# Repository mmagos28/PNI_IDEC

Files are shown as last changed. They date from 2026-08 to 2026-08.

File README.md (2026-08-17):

# PNI_IDEC
Central repository for IDEC documentation, design files, software, procedures, and technical resources supporting engineering, prototyping, fabrication, and research projects.
## License

This design folder is licensed under the CERN Open Hardware Licence Version 2 - Permissive (CERN-OHL-P-2.0). See [LICENSE](LICENSE) for the full license text.

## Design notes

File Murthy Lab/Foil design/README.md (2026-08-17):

# Foil Design

This folder contains the design files for the foil used with the fly holder assembly jig.

## Files

- `FlyMetal_AL_M_S Drawing v2.pdf`: manufacturing drawing.
- `FlyMetal_AL_M_S.f3d`: Fusion 360 design file.
- `FlyMetal_AL_M_S.step`: STEP file for CAD review or manufacturing workflows.

## Manufacturing Notes

- Tolerances: +/- 0.002 in.
- Material: 0.001 in stainless steel 316, annealed.
## License

This design folder is licensed under the CERN Open Hardware Licence Version 2 - Permissive (CERN-OHL-P-2.0). See [LICENSE](LICENSE) for the full license text.

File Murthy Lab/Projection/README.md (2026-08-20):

# Projection Calibration Code

This folder contains MATLAB code for calibrating the dome projection system. The main workflow is controlled from `ConfigureProjectorOnline.m`, which lets the user enter the physical measurements of the system, update calibration parameters, preview the projection geometry, and generate the `calibratedBallImage.data` file used by the projection pipeline.

Before running the code, download this full `Projection` folder to your computer and work from the local copy. MATLAB must be able to access the `.m`, `.fig`, `.mat`, `.data`, and `v2` files from the same local folder structure.

## Main Files

- `ConfigureProjectorOnline.m`: main calibration GUI. This is the recommended entry point.
- `generateDome_MASM.m`: computes the dome/mirror/projector geometry and writes `calibratedBallImage.data`.
- `coords.mat`: stores the current calibration coordinates used by the GUI.
- `calibratedBallImage.data`: generated calibration map.
- `v2/generateCalibrationPatternV2.m`: visual grid helper used as an auxiliary calibration view.

## Screen Dimension Reference

The Mini VR projection documentation describes the dome screen as a styrofoam sphere with an 18 inch outer diameter and a 16 inch inner diameter. Therefore, the default spherical screen radius used in this calibration folder is `proj_param_Rs = 8` inches.

Reference: https://braincogs.github.io/building/projection.html

The screen center coordinates (`proj_param_xsm`, `proj_param_ysm`, `proj_param_zsm`) still need to be measured on the actual rig relative to the animal eyes. The documentation provides the screen size, but not the final center position for each assembled setup.
## Basic Workflow

1. Measure the original physical geometry of the projection system.

   Measure the screen, mirror, and projector positions as carefully as possible. The calibration depends on these values, so the initial geometry should be based on the real system rather than guessed values.

2. Open the calibration GUI in MATLAB.

   ```matlab
   cd('C:\Users\ms2910\OneDrive - Princeton University\Documents\GitHub\IDEC\PNI_IDEC\Murthy Lab\Projection')
   ConfigureProjectorOnline
   ```

3. Enter the measured values in the corresponding fields.

   The main coordinate groups are:

   - `screenRadius`, `screenX`, `screenY`, `screenZ`
   - `mirrorRadius`, `mirrorX`, `mirrorY`, `mirrorZ`
   - `projectorX`, `projectorY`, `projectorZ`
   - `x0`, `y0`, `x1`, `y1`, `x2`, `y2`

   The screen, mirror, and projector values describe the physical layout. The `x0/y0`, `x1/y1`, and `x2/y2` values are used to scale and shift the projected coordinates during calibration.

4. Regenerate the projection.

   Press the regenerate button in the GUI. In the normal dome mode, the code calls `generateDome_MASM.m`, updates the projection figure, and writes `calibratedBallImage.data`.

5. Save the coordinates.

   Use the save option in the GUI after the system is aligned. The values are stored in `coords.mat` and loaded again the next time the GUI is opened.

## Visual Grid Mode

`ConfigureProjectorOnline.m` includes a `Visual grid` checkbox. This mode is intended as an auxiliary calibration view.

- When `Visual grid` is off, the GUI uses the normal dome calibration workflow and generates `calibratedBallImage.data`.
- When `Visual grid` is on, the GUI draws a polar azimuth/elevation grid using the same dome/mirror/projector geometry. This makes it easier to see how changes in the calibration parameters affect the projected image.

The visual grid is not a replacement for the final calibration file. It is a reference pattern to help align the system before returning to the normal dome mode and generating the final `calibratedBallImage.data`.

## Notes

- Start with accurate physical measurements, then use the GUI controls for fine adjustment.
- If the displayed projection does not update after code changes, clear MATLAB's cached functions:

  ```matlab
  close all force
  clear ConfigureProjectorOnline generateDome_MASM generateCalibrationPatternV2
  rehash toolboxcache
  ConfigureProjectorOnline
  ```

- `visualizeCalibratedBallImage.m` is kept as a manual debugging tool, but it is no longer opened automatically during calibration.

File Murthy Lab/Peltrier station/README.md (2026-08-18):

# Peltier Station

This folder contains CAD files and reference images for a Peltier-based station used with fly holders. The design provides a working platform for positioning the fly holder over a temperature-controlled Peltier module while keeping the surrounding setup accessible for imaging, manipulation, and alignment.

## Files

- `base-peltrier-station.step`: editable CAD model for the station base.
- `base-peltrier-station.stl`: mesh file for manufacturing the station base.
- `Fly-Holder-peltrier-station.step`: editable CAD model for the fly holder interface.
- `Fly-Holder-peltrier-station.stl`: mesh file for manufacturing the fly holder interface.
- `peltrier-station-new_prices_only.xlsx`: price list / bill of materials reference for the station components.

## Design Preview

<table>
  <tr>
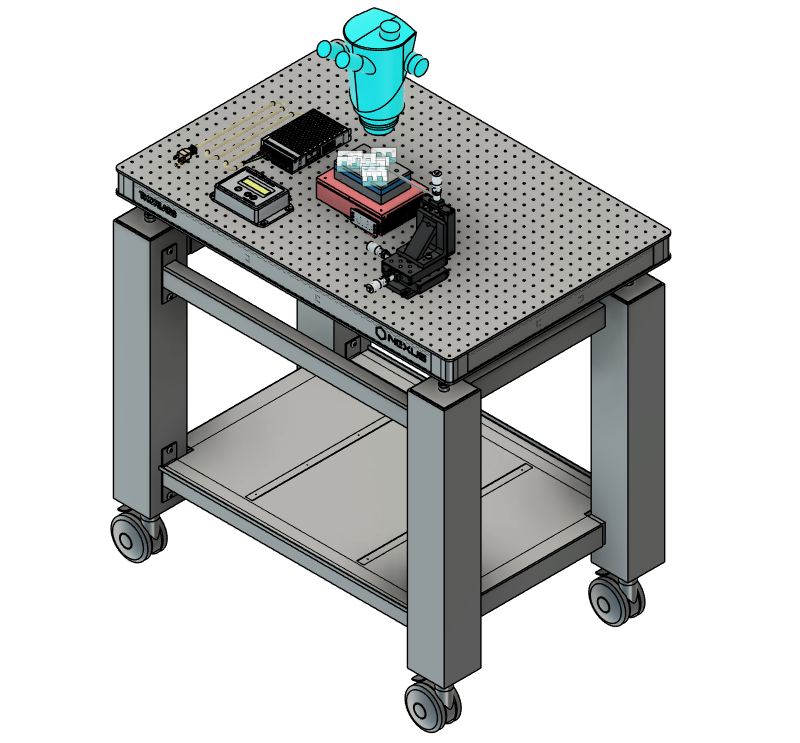
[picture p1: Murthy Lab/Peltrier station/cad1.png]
Peltier station CAD overview
    <td align="center"><br>Station overview</td>
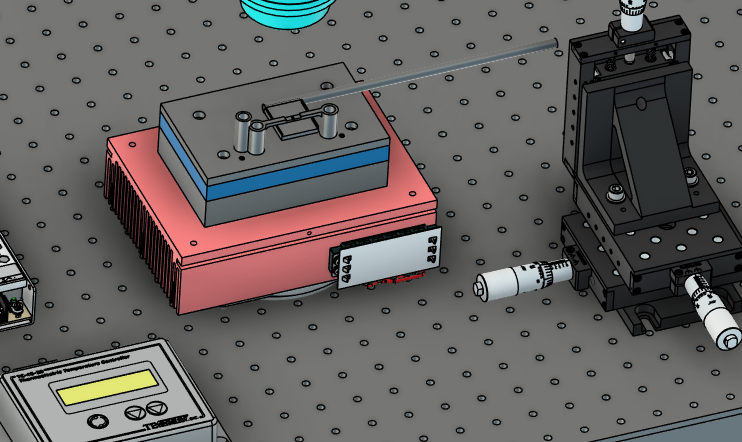
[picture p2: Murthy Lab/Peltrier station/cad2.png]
Peltier module and fly holder detail
    <td align="center"><br>Peltier and holder detail</td>
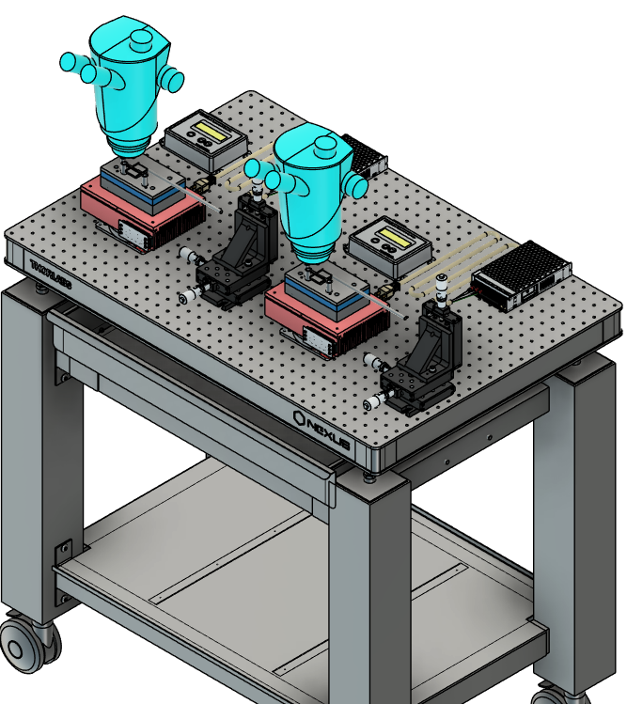
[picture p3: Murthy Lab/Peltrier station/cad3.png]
Dual station CAD layout
    <td align="center"><br>Dual station layout</td>
  </tr>
</table>

## Manufacturing Notes

Use the `.step` files when the design needs to be edited or adapted before fabrication. Use the `.stl` files when preparing the parts for 3D printing or mesh-based manufacturing.

Before manufacturing, inspect the CAD model orientation, mounting surfaces, and holder interface features. Support placement should avoid critical alignment faces whenever possible, especially where the fly holder seats into the station.

After fabrication, clean the parts according to the manufacturing method used. For resin 3D printed parts, remove uncured resin, fully dry the parts, cure them according to the material recommendations, and remove supports carefully. Light sanding may be useful on support contact areas or sliding interfaces if the holder fit is tight.

## License

This design folder is licensed under the CERN Open Hardware Licence Version 2 - Permissive (CERN-OHL-P-2.0). See [LICENSE](LICENSE) for the full license text.

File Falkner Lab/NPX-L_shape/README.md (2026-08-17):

# NPX-L Shape

<!-- IMAGE_GALLERY_START -->
## Image Gallery

The images below provide a quick visual reference for the files in this folder.

### NPX Holder L Shape

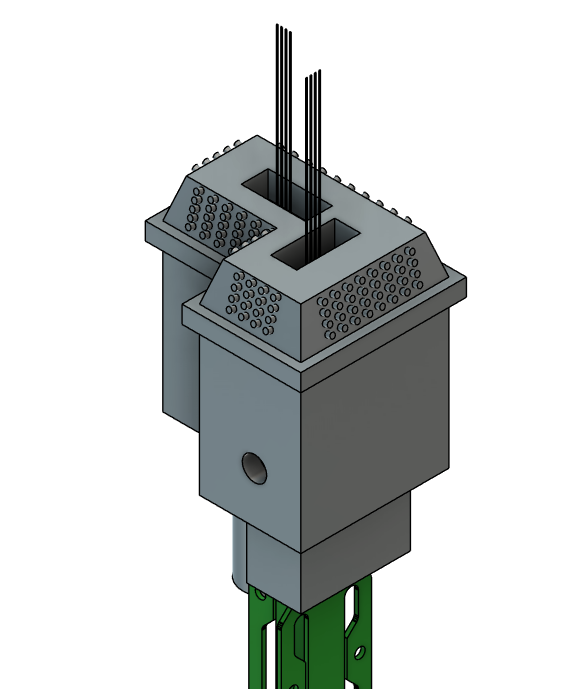
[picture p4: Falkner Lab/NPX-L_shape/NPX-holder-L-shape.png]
NPX Holder L Shape


### NPX Holder L Shape 1

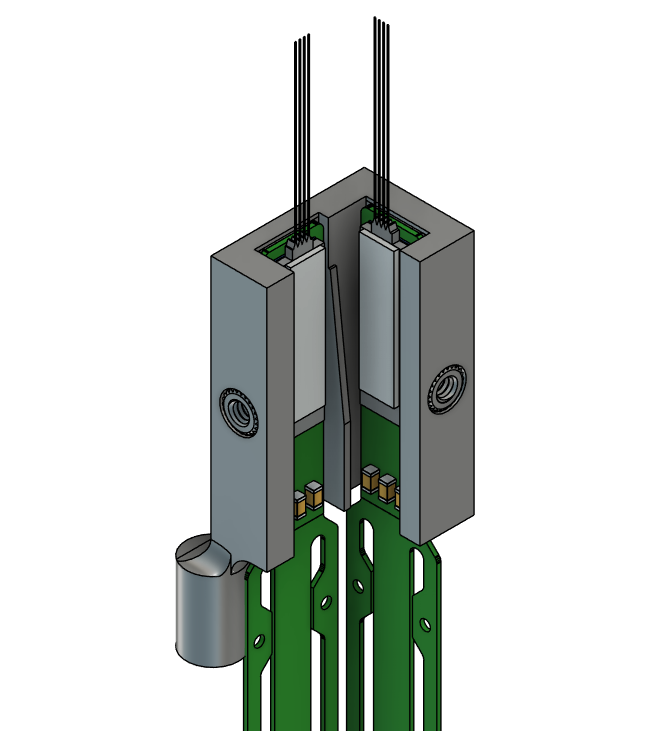
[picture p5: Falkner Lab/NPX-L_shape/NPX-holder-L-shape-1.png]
NPX Holder L Shape 1


### NPX Holder L Shape Stage

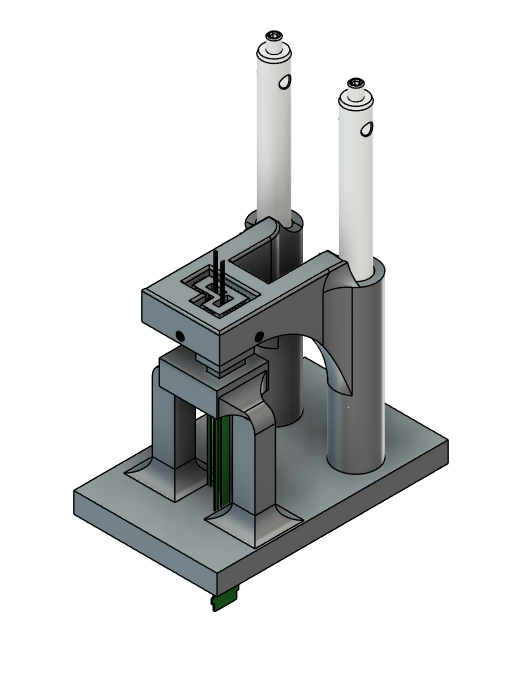
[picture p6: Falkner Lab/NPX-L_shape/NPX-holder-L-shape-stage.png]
NPX Holder L Shape Stage


<!-- IMAGE_GALLERY_END -->
## License

This design folder is licensed under the CERN Open Hardware Licence Version 2 - Permissive (CERN-OHL-P-2.0). See [LICENSE](LICENSE) for the full license text.

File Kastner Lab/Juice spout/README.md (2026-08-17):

# Juice Spout
## Materials
Brass Barbed Hose Fitting for Air and Water
Straight Adapter for 1/8" Hose ID, 1/8 NPTF Male
https://eprocurement.mcmaster.com/5346K61/?publication=ecmrc&pnchstp=2&combine_content=true

Tight-Seal Barbed Tube Fitting for Air and Water
Nylon Straight Adapter for 1/8" Tube ID, 10-32 Male
https://eprocurement.mcmaster.com/5463K53-2974K117/?publication=ecmrc&pnchstp=2&combine_content=true

<!-- IMAGE_GALLERY_START -->
## Image Gallery

The image below provides a quick visual reference for the files in this folder.

### Juice Spout

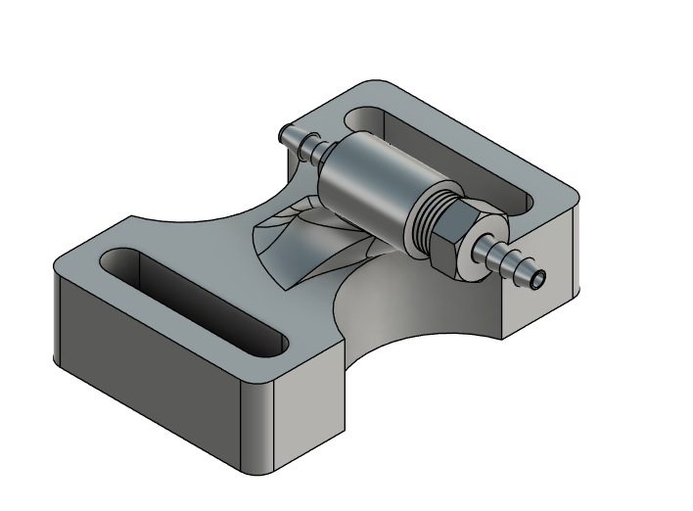
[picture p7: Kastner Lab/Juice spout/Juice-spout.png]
Juice Spout


<!-- IMAGE_GALLERY_END -->
## License

This design folder is licensed under the CERN Open Hardware Licence Version 2 - Permissive (CERN-OHL-P-2.0). See [LICENSE](LICENSE) for the full license text.

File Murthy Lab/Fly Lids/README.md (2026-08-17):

# Fly Lids

## Materials

- Clear easy-to-form PETG sheet, 6 in x 6 in x 1/8 in.
- Reference material: [McMaster-Carr 85815K114](https://eprocurement.mcmaster.com/85815K114/?publication=ecmrc&pnchstp=2&combine_content=true).
- Water-resistant sandpaper.

## Mold Preparation

1. Print the mold pieces at 0.025 mm layer resolution, using the highest available resolution for the printer.

2. Wash the printed mold pieces to remove uncured resin.

3. Cure the pieces according to the resin manufacturer's recommendations.

4. Once the parts are fully cured, use water-resistant sandpaper to smooth the cup area of the mold. This step helps remove visible layer lines from the print and produces a more uniform surface for shaping the PETG.

## PETG Lid Forming

1. Print the cutting template from the provided Adobe Illustrator file (`PETG-design-lids.ai`).

2. Cut the PETG sheet according to the template.

3. Once each plastic piece has been cut to the correct size, clean the surface of `Fly_lid_PETG_mold_p1.stl` and place the PETG on top of it.

4. Use a heat gun to gradually soften the PETG in the curved area. Apply heat slowly and evenly to avoid burning, warping, or overheating the material.

5. Once the PETG has softened, press it into shape using `Fly_lid_PETG_mold_p2.stl`.

6. Hold the mold in position until the PETG cools completely and keeps its shape.

7. If the final shape is not uniform, repeat the heating and pressing process as needed.

<!-- IMAGE_GALLERY_START -->
## Image Gallery

The images below provide a quick visual reference for the files in this folder.

### Fly Lid PETG Mold

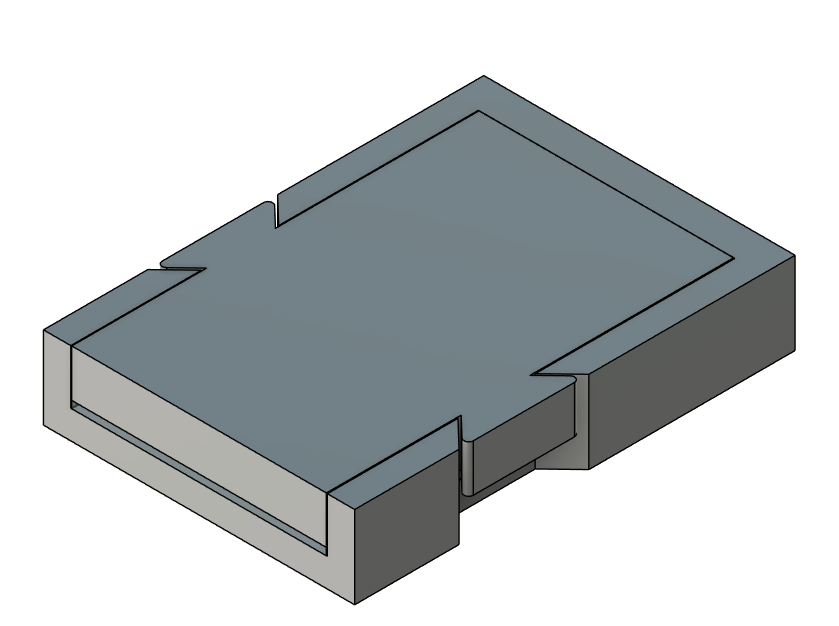
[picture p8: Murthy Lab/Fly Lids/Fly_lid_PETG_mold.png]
Fly Lid PETG Mold


### Fly Lid PETG Mold Interior

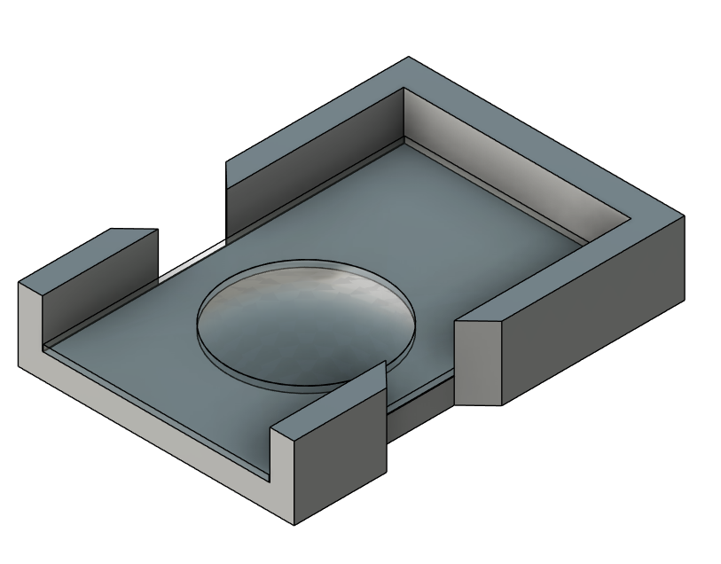
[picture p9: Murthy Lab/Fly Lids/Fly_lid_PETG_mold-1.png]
Fly Lid PETG Mold Interior


### Fly Stage for Lids

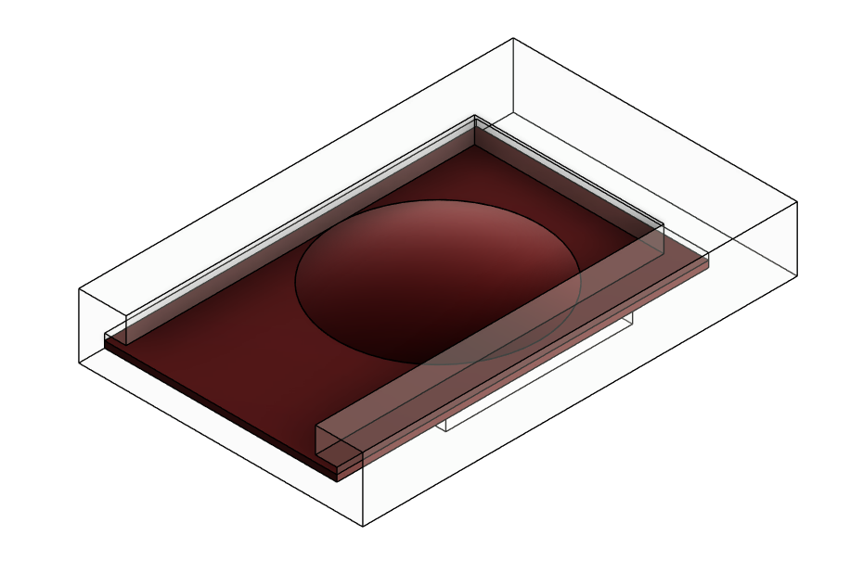
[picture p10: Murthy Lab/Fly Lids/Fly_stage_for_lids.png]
Fly Stage for Lids


<!-- IMAGE_GALLERY_END -->
## License

This design folder is licensed under the CERN Open Hardware Licence Version 2 - Permissive (CERN-OHL-P-2.0). See [LICENSE](LICENSE) for the full license text.

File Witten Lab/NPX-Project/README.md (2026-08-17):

# Neuropixels 2.0 Implant Designs

This folder contains 3D-printable implant designs for Neuropixels 2.0 multi-shank probes. The designs were manufactured on a Formlabs Form 4BL SLA 3D printer using Precision and Clear material at a layer resolution of 0.05 mm.

For detailed assembly instructions, refer to the [Neuropixels 2.0 two-probe implant assembly guide](https://github.com/mmagos28/PNI_IDEC/blob/main/Witten%20Lab/NPX-Project/Neuropixels_2.0_Implant_two_probes_Assembly_Witten.docx.pdf).

The highest available printer resolution was not used intentionally. In practice, the relevant tolerances varied between Neuropixels probes and during post-processing of the printed parts. For this reason, 0.05 mm was selected as the standard manufacturing resolution for these components.

## Design Rationale

Unlike many implant models, this project prioritizes two goals at the same time: recovering the Neuropixels probe at the end of the study and maintaining a chronic implant configuration that preserves the repeatability of recordings from day to day.

This is especially important for double-probe implants. In many conventional double implants, both probes are fixed together. If one shank or probe fails at the end of an experiment, the bonded assembly can make it very difficult to reuse the unaffected probe. The designs in this folder propose a modular double-implant approach in which each Neuropixels probe has its own holder. If one probe or holder is damaged, the unaffected component can be recovered more easily.

## Folder Organization

The designs are organized into two main categories for Neuropixels 2.0 multi-shank probes:

- `Dovetail`: for probes with a metal cap.
- `No Dovetail`: for probes with a silicon cap.

## Dovetail Designs

The dovetail designs include both single-holder and double-holder configurations.

### Single Holder

The single-holder design allows the experimenter to secure and store the cable easily without requiring the headstage to be included in the implant. This holder is intentionally compact, reducing both the space occupied on the mouse's head and the overall implant weight.

### Double Holder

The double-holder design is intended to increase the number of recording sites within a defined brain area. The spacing between probes can also be adjusted depending on the needs of the experiment.

Current dovetail double-holder designs include the following distances between Neuropixels shanks:

- 2.5 mm
- 2.7 mm
- 2.9 mm
- 3.5 mm

For Neuropixels probes with a metal cap, 2.5 mm is currently the minimum shank-to-shank distance achieved with this design.

## No Dovetail Designs

The no-dovetail holder is intended for Neuropixels probes with a silicon cap. Under this configuration, the closest shank-to-shank spacing achieved so far is 1.5 mm.
## License

This design folder is licensed under the CERN Open Hardware Licence Version 2 - Permissive (CERN-OHL-P-2.0). See [LICENSE](LICENSE) for the full license text.

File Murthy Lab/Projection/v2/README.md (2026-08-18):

# Projection Calibration Pattern V2

This folder contains a standalone MATLAB prototype for generating a visual dome-style calibration grid entirely from code. It does not replace the current `ConfigureProjectorOnline` workflow or the `calibratedBallImage.data` generation process.

## Files

- `generateCalibrationPatternV2.m`: function that draws the polar grid pattern.
- `showCalibrationPatternV2.m`: simple script that opens the pattern full-screen.

## Basic Use

From MATLAB, run:

```matlab
cd('C:\Users\ms2910\OneDrive - Princeton University\Documents\GitHub\IDEC\PNI_IDEC\Murthy Lab\Projection\v2')
showCalibrationPatternV2
```

To send it to another monitor/projector, change `MonitorIndex` in `showCalibrationPatternV2.m`.

## Adjustable Parameters

The pattern is generated with rings, radial lines, labels, and a center mask. Useful parameters include:

```matlab
generateCalibrationPatternV2( ...
    'FullScreen', true, ...
    'MonitorIndex', 2, ...
    'RingStep', 0.08, ...
    'AngleStep', 10, ...
    'CenterHoleRadius', 0.085);
```

- `RingStep`: spacing between circular rings.
- `AngleStep`: angular spacing between radial lines.
- `MonitorIndex`: monitor/projector target.
- `CenterHoleRadius`: radius of the black center opening.

## Notes

This version is meant to make visual calibration easier before modifying the current projection pipeline. Once the visual pattern is useful, the same drawing logic can be connected to `ConfigureProjectorOnline` as a selectable calibration mode.

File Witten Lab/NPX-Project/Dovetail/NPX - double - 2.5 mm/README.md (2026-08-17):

# NPX - double - 2.5 mm

## Printing Notes

- The ready-to-print setup file in this folder is the `.form` file: `full-parts-npx-double-2_5mm.form`.
- Print these parts at 0.05 mm layer resolution.
- Before printing and assembly, follow the initial protocol in the [Neuropixels 2.0 two-probe implant assembly guide](../../Neuropixels_2.0_Implant_two_probes_Assembly_Witten.docx.pdf).

<!-- IMAGE_GALLERY_START -->
## Image Gallery

The images below provide a quick visual reference for the files in this folder.

### Npx Double 2.5 Mm Iso Stage

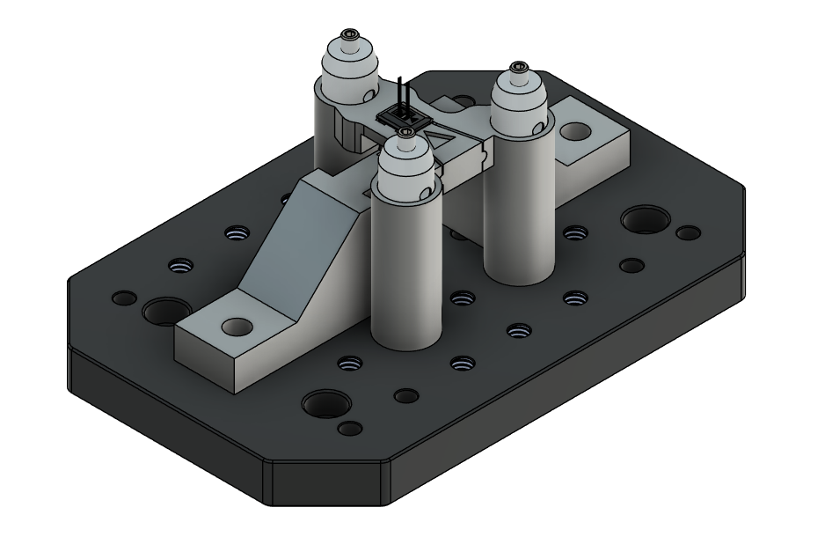
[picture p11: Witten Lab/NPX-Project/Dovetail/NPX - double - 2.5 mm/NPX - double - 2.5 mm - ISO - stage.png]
Npx Double 2.5 Mm Iso Stage


### Npx Double 2.5 Mm Iso

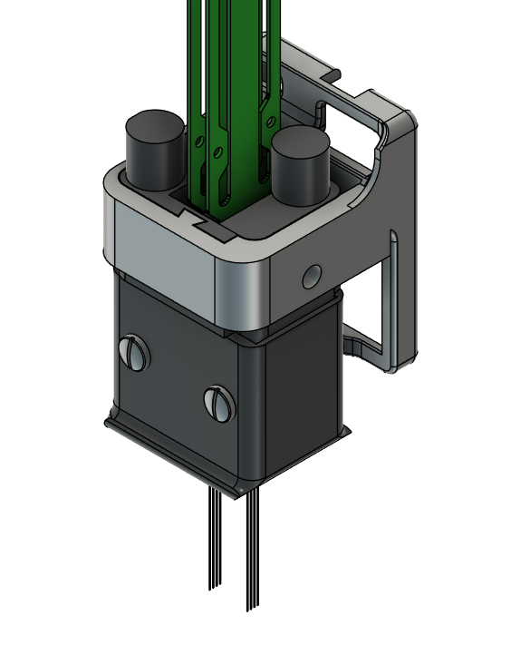
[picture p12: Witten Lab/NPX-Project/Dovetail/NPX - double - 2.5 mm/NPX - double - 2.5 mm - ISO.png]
Npx Double 2.5 Mm Iso


### Npx Double 2.5 Mm Sideview

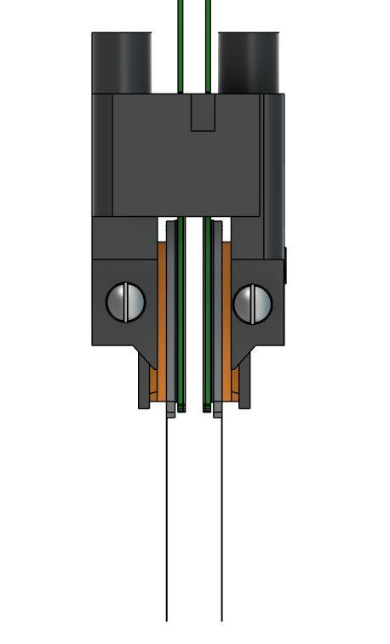
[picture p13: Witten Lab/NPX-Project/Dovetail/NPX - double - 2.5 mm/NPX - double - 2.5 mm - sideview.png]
Npx Double 2.5 Mm Sideview


<!-- IMAGE_GALLERY_END -->

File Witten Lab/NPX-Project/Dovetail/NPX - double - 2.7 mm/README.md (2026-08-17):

# NPX - double - 2.7 mm

## Printing Notes

- The ready-to-print setup file in this folder is the `.form` file: `NPX - double - 2.7 mm.form`.
- Print these parts at 0.05 mm layer resolution.
- Before printing and assembly, follow the initial protocol in the [Neuropixels 2.0 two-probe implant assembly guide](../../Neuropixels_2.0_Implant_two_probes_Assembly_Witten.docx.pdf).

<!-- IMAGE_GALLERY_START -->
## Image Gallery

The images below provide a quick visual reference for the files in this folder.

### Npx Double 2.7 Mm Iso Stage

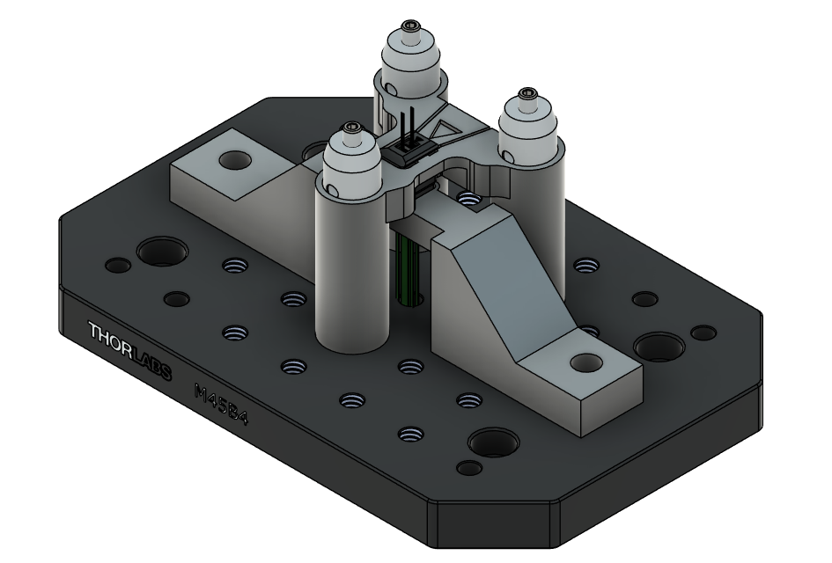
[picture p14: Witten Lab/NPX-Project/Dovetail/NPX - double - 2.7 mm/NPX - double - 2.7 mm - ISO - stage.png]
Npx Double 2.7 Mm Iso Stage


<!-- IMAGE_GALLERY_END -->

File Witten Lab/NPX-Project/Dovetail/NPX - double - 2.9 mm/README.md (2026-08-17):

# NPX - double - 2.9 mm

## Printing Notes

- The ready-to-print setup file in this folder is the `.form` file: `29mm-lingwei.form`.
- Print these parts at 0.05 mm layer resolution.
- Before printing and assembly, follow the initial protocol in the [Neuropixels 2.0 two-probe implant assembly guide](../../Neuropixels_2.0_Implant_two_probes_Assembly_Witten.docx.pdf).

<!-- IMAGE_GALLERY_START -->
## Image Gallery

The images below provide a quick visual reference for the files in this folder.

### Npx Double 2.9 Mm Iso Stage

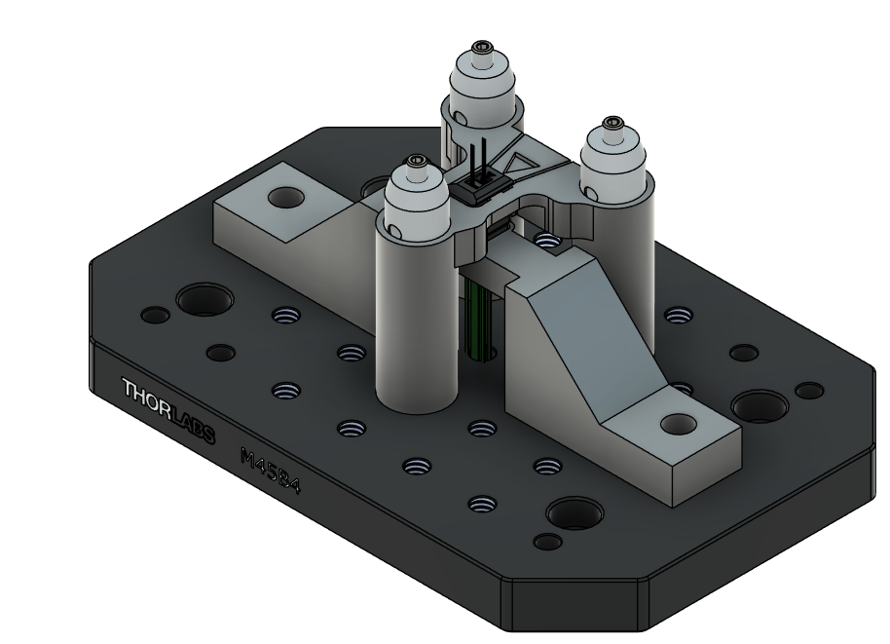
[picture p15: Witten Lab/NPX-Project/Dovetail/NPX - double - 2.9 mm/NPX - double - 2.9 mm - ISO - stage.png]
Npx Double 2.9 Mm Iso Stage


### Npx Double 2.9 Mm Sideview

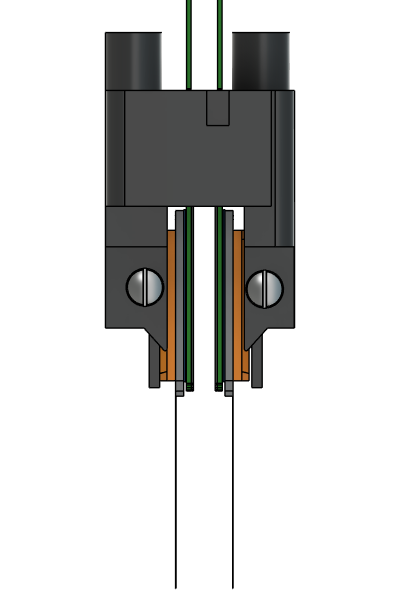
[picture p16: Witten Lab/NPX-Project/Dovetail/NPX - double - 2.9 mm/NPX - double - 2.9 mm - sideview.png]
Npx Double 2.9 Mm Sideview


<!-- IMAGE_GALLERY_END -->

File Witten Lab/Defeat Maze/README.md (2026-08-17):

# Defeat Maze

<!-- IMAGE_GALLERY_START -->
## Image Gallery

The image below provides a quick visual reference for the files in this folder.

### Defeat Maze

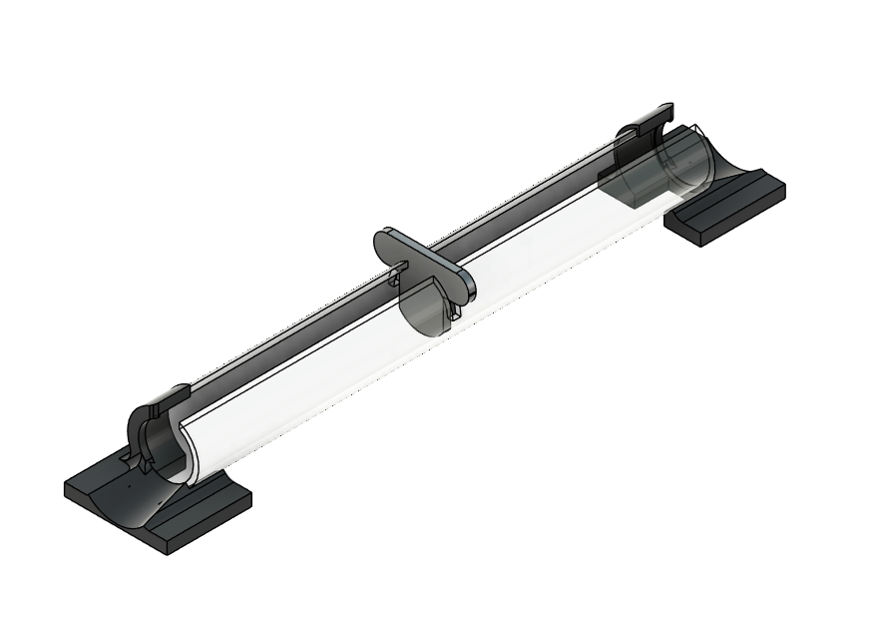
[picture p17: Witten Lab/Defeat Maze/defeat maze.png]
Defeat Maze


<!-- IMAGE_GALLERY_END -->
## License

This design folder is licensed under the CERN Open Hardware Licence Version 2 - Permissive (CERN-OHL-P-2.0). See [LICENSE](LICENSE) for the full license text.

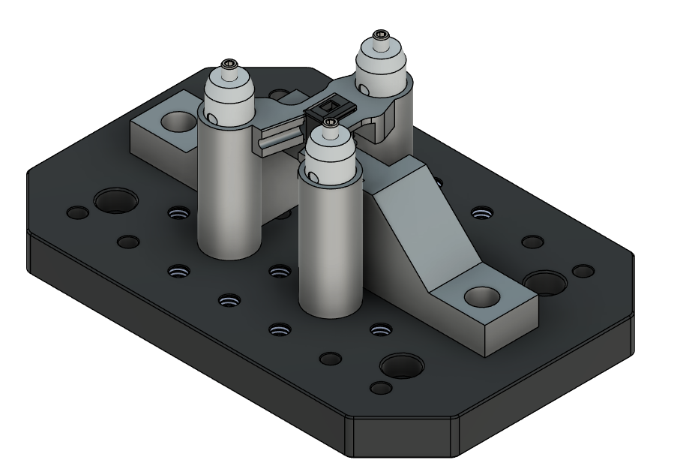
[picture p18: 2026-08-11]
Witten Lab/NPX-Project/Dovetail/NPX - double - 3.5 mm/NPX - double - 3.5 mm - stage .png

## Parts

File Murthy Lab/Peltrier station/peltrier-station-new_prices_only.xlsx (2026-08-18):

Part Name | peltrier-station-new
Working BOM | as of August 17, 2026 at 5:43:05 PM UTC
Exported by | ms2910@princeton.edu
Time of Export | 5:43 PM Aug 17, 2026
Level | Part Number | Part Name | Description | Quantity | Change Order | Unit Price (USD) | Extended Price (USD) | Price Source | Source URL
1.1 | POC001 - Optics a la Cart | POC001-Step | STEP AP203 | 1 |  | $1543.75 | $1543.75 | Thorlabs cart screenshot
1.3 | 8 | CP-065 | Alibre Inc. | 1 |  | $339.00 | $339.00 | TE Technology cart screenshot
1.4 | 8 | PS-24-6.5A | Alibre Inc. | 1 |  | $55.00 | $55.00 | TE Technology cart screenshot
1.5 | 8 | TC-48-20 | Alibre Inc. | 1 |  | $535.00 | $535.00 | TE Technology cart screenshot
1.7 | 2865-E0W | PT3-Step | STEP AP214 | 1 |  | $1124.89 | $1124.89 | Thorlabs cart screenshot
1.8 | B2436T | B2436T-Step | STEP AP203 | 1 |  | $1511.50 | $1511.50 | Thorlabs cart screenshot
 |  |  |  |  | Estimated Total |  | $5109.14

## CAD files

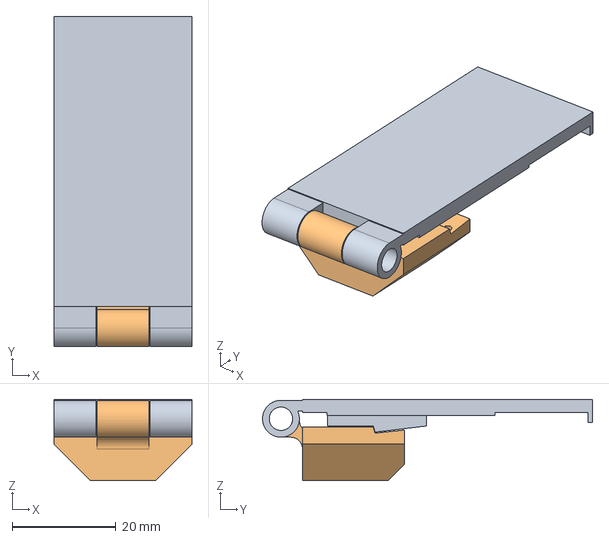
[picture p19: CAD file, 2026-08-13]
Murthy Lab/Fly Holder Assembly Jig/Backward_Orientation/Backward assembly jig.step
26.5 x 63.5 x 15.6 mm

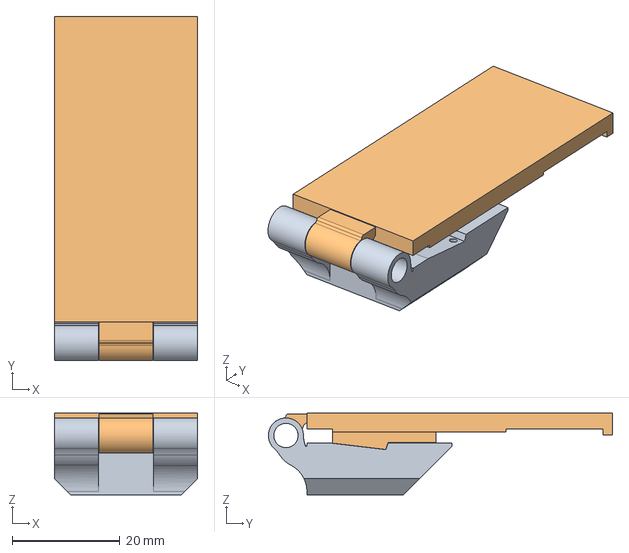
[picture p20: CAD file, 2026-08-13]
Murthy Lab/Fly Holder Assembly Jig/Forward_Orientation/Forward Assemble jig.step
26.5 x 63.8 x 15.1 mm

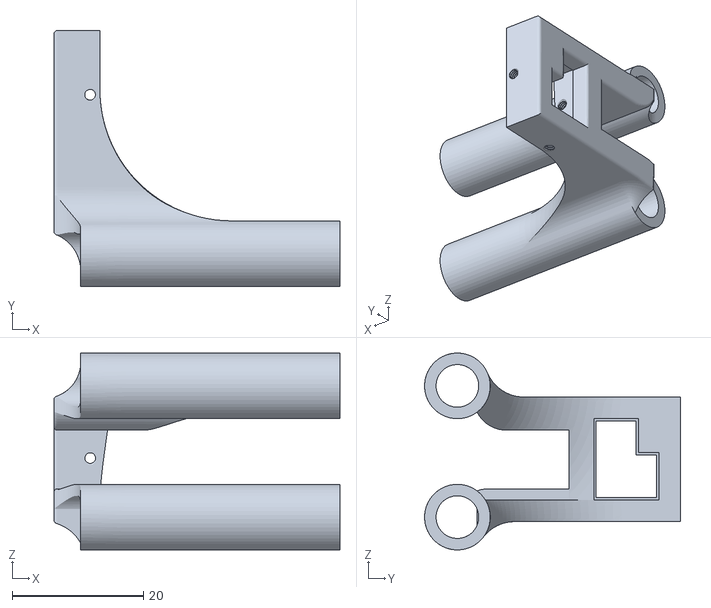
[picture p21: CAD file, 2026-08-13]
Falkner Lab/NPX-L_shape/stage-part2.stl
43.6 x 39.0 x 30.0

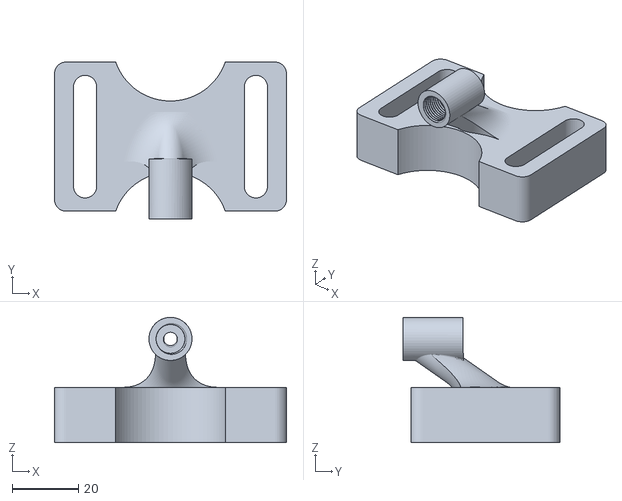
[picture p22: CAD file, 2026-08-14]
Kastner Lab/Juice spout/Juice-spout.stl
70.0 x 47.3 x 37.8

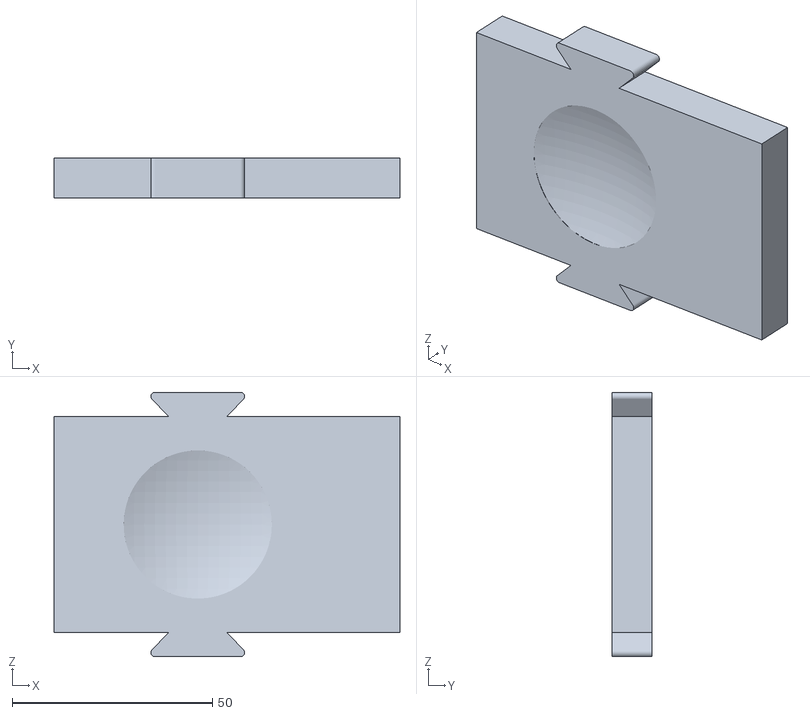
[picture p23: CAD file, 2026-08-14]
Murthy Lab/Fly Lids/Fly_lid_PETG_mold_p2.stl
86.4 x 10.00 x 66.0

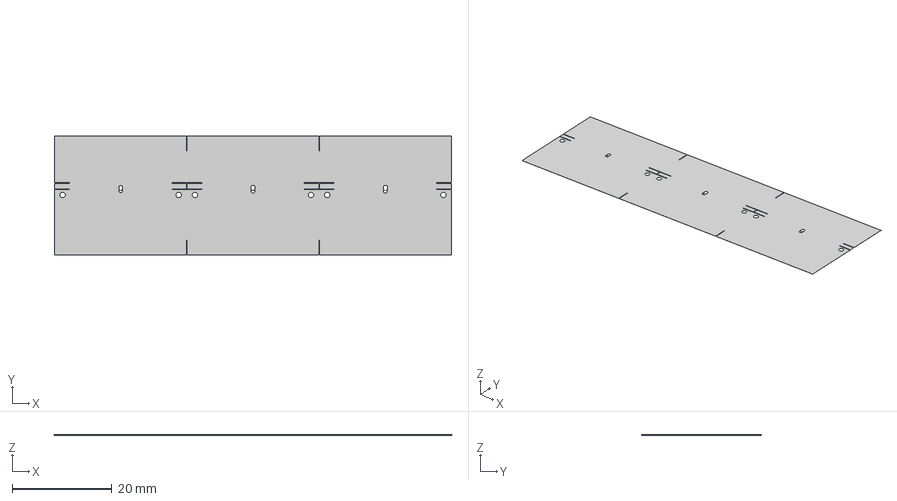
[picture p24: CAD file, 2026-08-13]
Murthy Lab/Foil design/FlyMetal_AL_M_S.step
79.5 x 23.9 x 0.01 mm

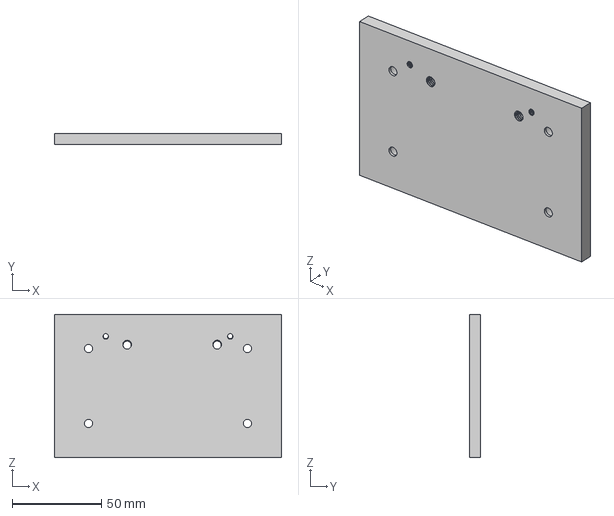
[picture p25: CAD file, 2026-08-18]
Murthy Lab/Peltrier station/base-peltrier-station.step
127.0 x 6.35 x 80.0 mm

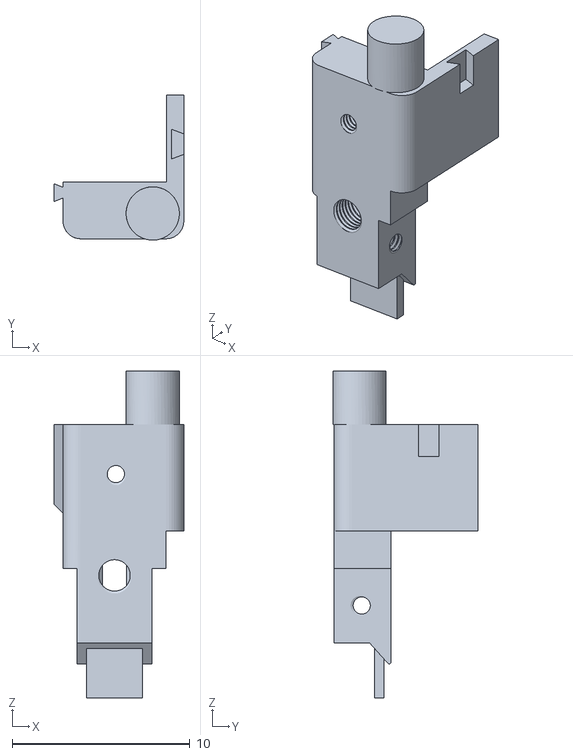
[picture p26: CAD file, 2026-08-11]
Witten Lab/NPX-Project/Dovetail/NPX - double - 2.5 mm/Component1.stl
7.30 x 8.17 x 18.4

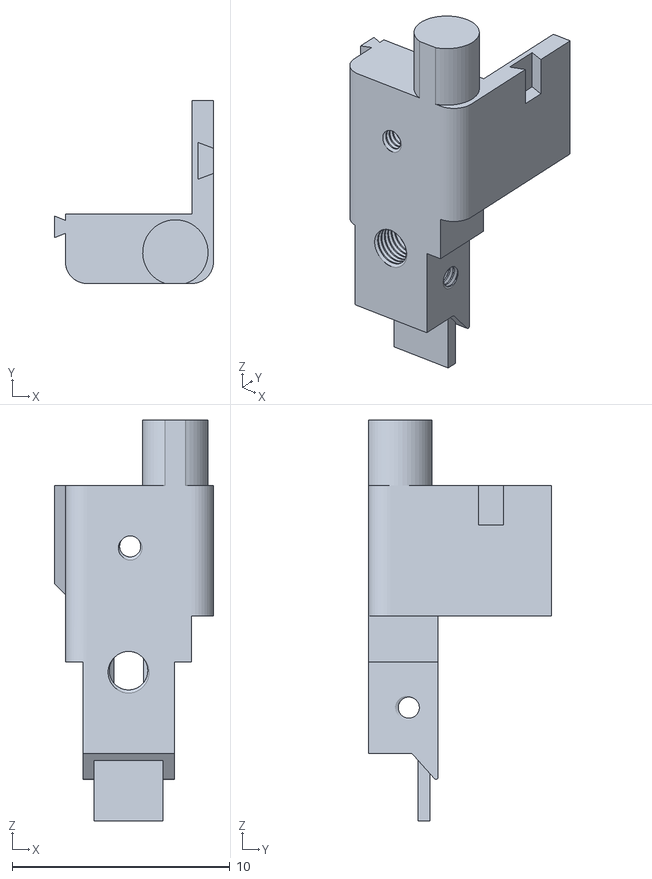
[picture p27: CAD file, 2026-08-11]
Witten Lab/NPX-Project/Dovetail/NPX - double - 2.7 mm/Component1.stl
7.30 x 8.40 x 18.4

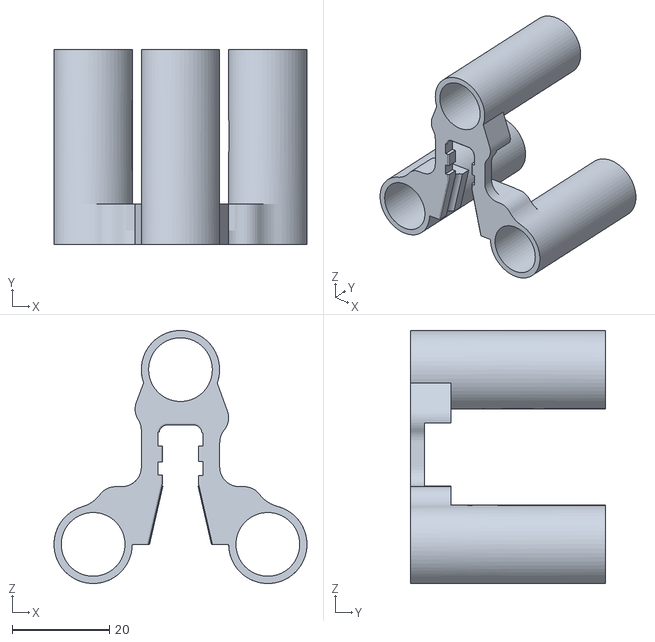
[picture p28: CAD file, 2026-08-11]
Witten Lab/NPX-Project/Dovetail/NPX - double - 2.9 mm/stage-p2.stl
52.0 x 40.0 x 52.0

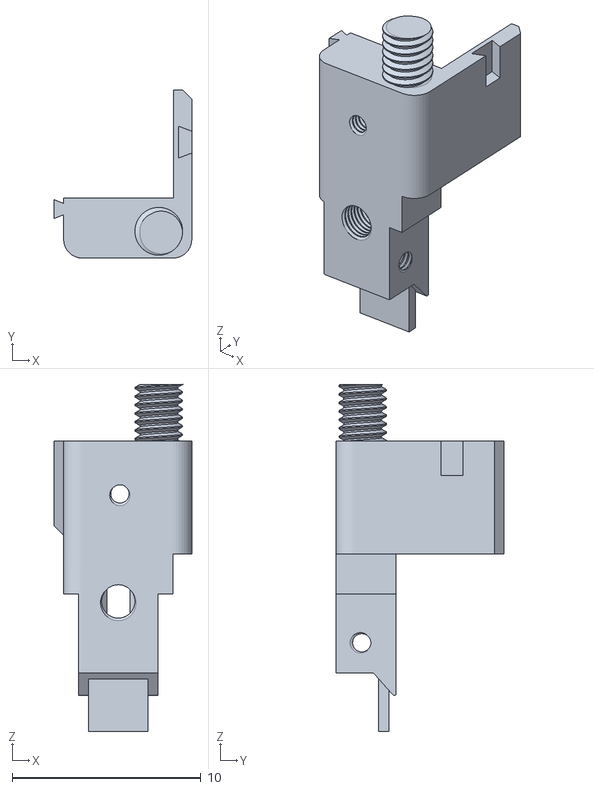
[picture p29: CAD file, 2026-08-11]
Witten Lab/NPX-Project/Dovetail/NPX - double - 3.5 mm/npx-p2.stl
7.30 x 8.92 x 18.4

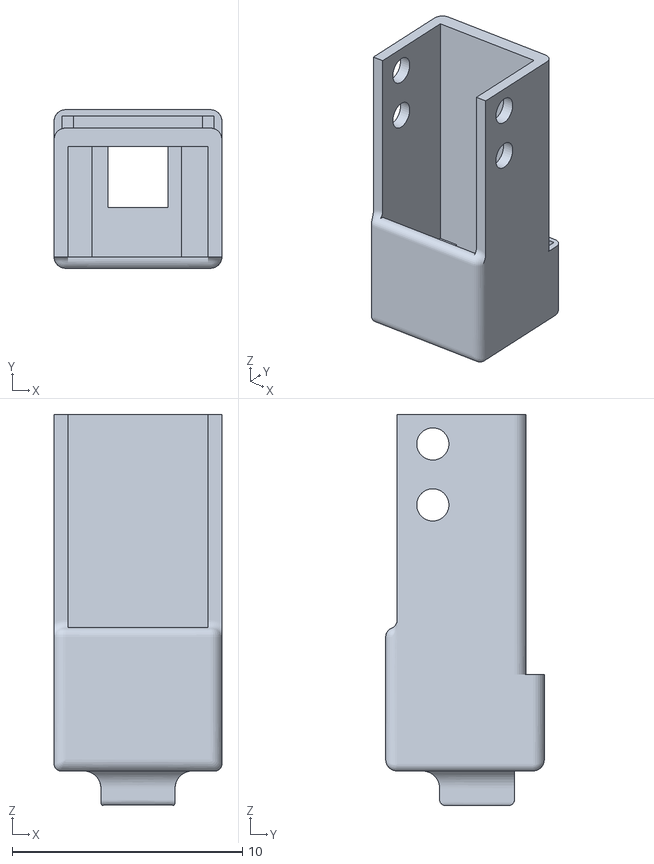
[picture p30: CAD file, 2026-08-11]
Witten Lab/NPX-Project/Dovetail/NPX - single - pocket/NPX - lid.stl
7.30 x 6.90 x 17.0

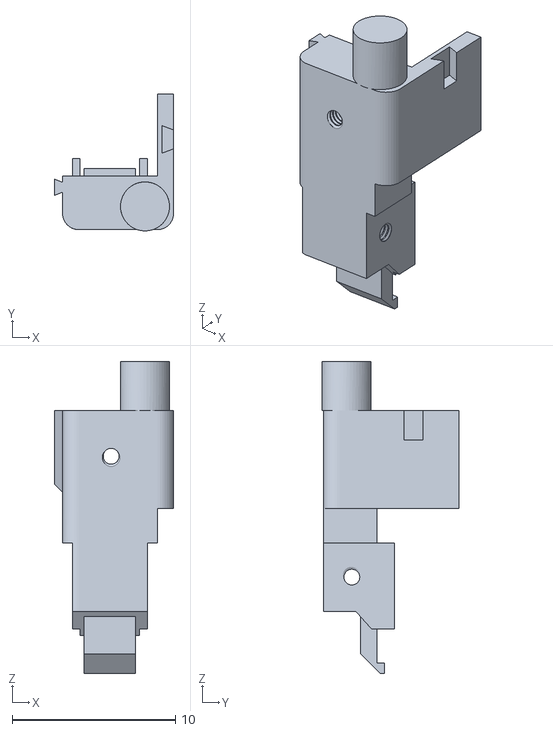
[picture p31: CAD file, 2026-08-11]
Witten Lab/NPX-Project/No Dovetail/npx-wings-15mm/npx-p1-nodovetail-wings-15mm.stl
7.30 x 8.37 x 19.1

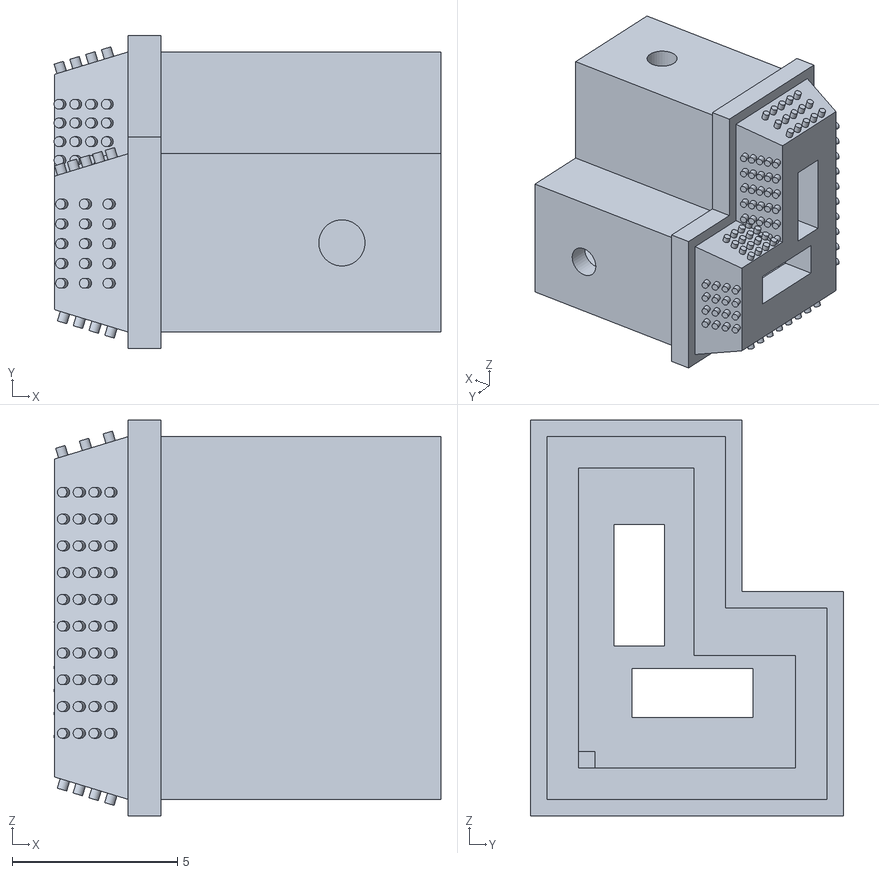
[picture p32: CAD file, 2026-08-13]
Falkner Lab/NPX-L_shape/NPX-holder-L-shape-part2.stl
11.7 x 9.48 x 12.0

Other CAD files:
Murthy Lab/Fly Holder Assembly Jig/Backward_Orientation/Backward_top.stl
Murthy Lab/Fly Holder Assembly Jig/Forward_Orientation/dissecting_chamber_AL_fwdv2 v6.stl
Murthy Lab/Fly Lids/Fly_stage_for_lids.stl
Murthy Lab/Peltrier station/Fly-Holder-peltrier-station.step
Falkner Lab/NPX-L_shape/NPX-holder-L-shape-part1.stl
Falkner Lab/NPX-L_shape/Stage-part1.stl
Murthy Lab/Fly Holder Assembly Jig/Backward_Orientation/Backward_base.stl
Murthy Lab/Fly Holder Assembly Jig/Backward_Orientation/dissecting-chamber-back.stl
Murthy Lab/Fly Holder Assembly Jig/Forward_Orientation/Forward_base.stl
Murthy Lab/Fly Holder Assembly Jig/Forward_Orientation/Forward_top.stl
Murthy Lab/Fly Lids/Fly_lid_PETG_mold_p1.stl
Murthy Lab/Foil design/FlyMetal_AL_M_S.f3d
Murthy Lab/Peltrier station/Fly-Holder-peltrier-station.stl
Murthy Lab/Peltrier station/base-peltrier-station.stl
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

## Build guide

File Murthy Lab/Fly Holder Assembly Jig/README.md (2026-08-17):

# Fly Holder Assembly Jig

This folder contains jig components for assembling fly holders. The parts were manufactured on a Formlabs Form 4BL SLA 3D printer using Gray resin at a layer resolution of 0.025 mm.

Two jig orientations are provided:

- `Backward_Orientation`
- `Forward_Orientation`

The experimenter can select the orientation that best matches the holder model and assembly workflow being used.

The foil used with this jig is documented in the [Foil design](../Foil%20design) folder.

## Printing Notes

- The ready-to-print setup files are the `.form` files:
  - `Backward_Orientation/Backward_printing_file.form`
  - `Forward_Orientation/Forward_printing_file.form`
- Print the jig components at 0.025 mm layer resolution.
- The position of the holders during printing is important. Support placement can affect the final alignment of the device, especially on surfaces that guide or register the holder during assembly. When preparing the print, avoid placing supports on critical alignment faces whenever possible.

## Cleaning and Curing

After printing, rinse the parts in isopropyl alcohol to remove uncured resin, then allow them to dry completely before curing. Cure the parts according to the resin manufacturer's recommendations for Gray material. Remove supports carefully after cleaning and curing, paying special attention to alignment surfaces and small features.

For the holder pieces, lightly sand the areas where support material was attached. This helps remove residual support marks and allows the holder to slide more smoothly into the assembly jig.

Once the pieces are clean, dry, fully cured, and sanded where needed, proceed with assembly.

## Assembly Procedure

1. Select the jig orientation that matches the model you want to assemble.

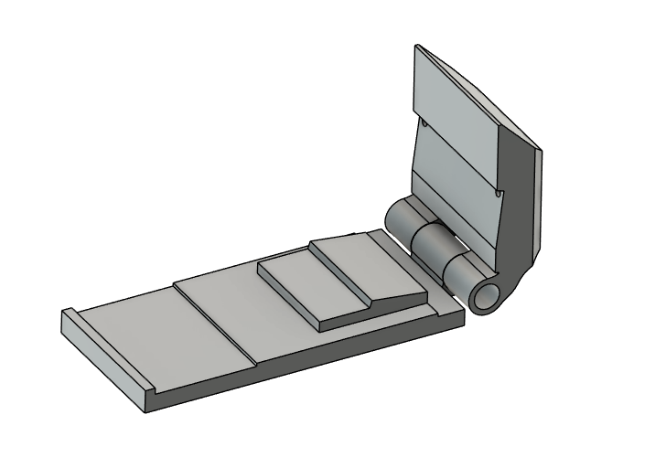
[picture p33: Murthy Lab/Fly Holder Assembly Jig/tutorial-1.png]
Select the jig model


2. Place the holder or dissection chamber inside the assembly jig.

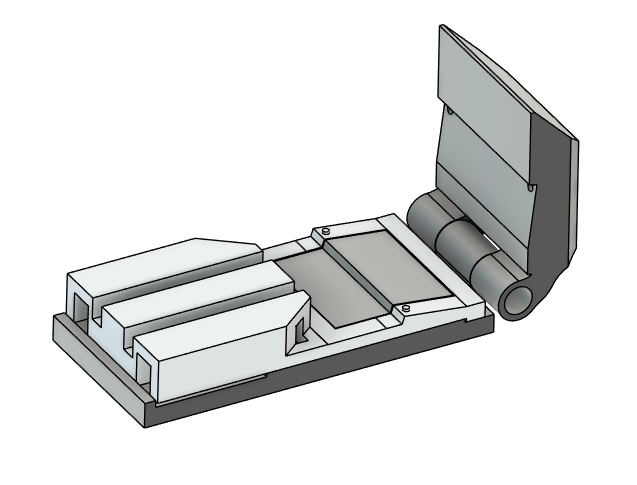
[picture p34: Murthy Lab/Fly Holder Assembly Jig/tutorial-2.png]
Place the holder in the jig


3. Cut the foil to the size required for the selected fly holder, using the design files in the [Foil design](../Foil%20design) folder as reference. Place the foil over the holder, align the perforated holes with the holder, and apply a small drop of cyanoacrylate glue, such as Crazy Glue, to each hole.

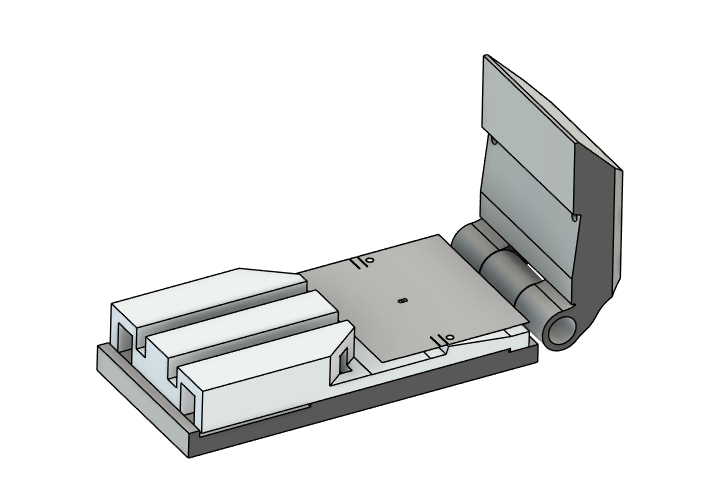
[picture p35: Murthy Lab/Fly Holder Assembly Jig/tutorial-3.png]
Align the foil and apply glue


4. Close the jig. This locks the foil position and creates the bends exactly where they are needed.

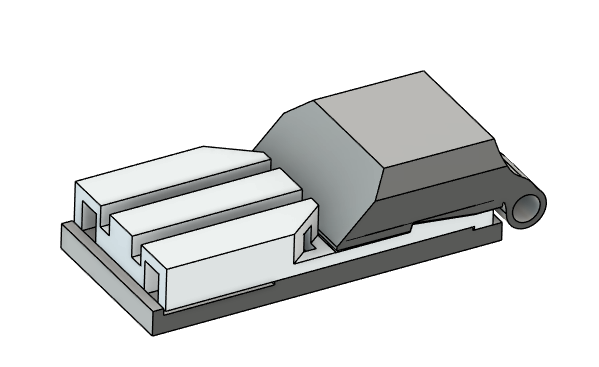
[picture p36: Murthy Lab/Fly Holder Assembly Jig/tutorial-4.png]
Close the jig


5. Once the foil is correctly positioned and fixed to the holder, apply epoxy around the foil edges. This seals the interface and helps prevent leaks, since liquid will be placed inside the holder during use.

6. Cure the epoxy according to the manufacturer's instructions.

7. After the epoxy is fully cured, the assembled holder is ready to use.
## License

This design folder is licensed under the CERN Open Hardware Licence Version 2 - Permissive (CERN-OHL-P-2.0). See [LICENSE](LICENSE) for the full license text.

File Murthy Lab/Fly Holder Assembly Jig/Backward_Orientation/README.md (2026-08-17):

# Backward_Orientation

<!-- IMAGE_GALLERY_START -->
## Image Gallery

The images below provide a quick visual reference for the files in this folder.

### Backward Assembly Jig

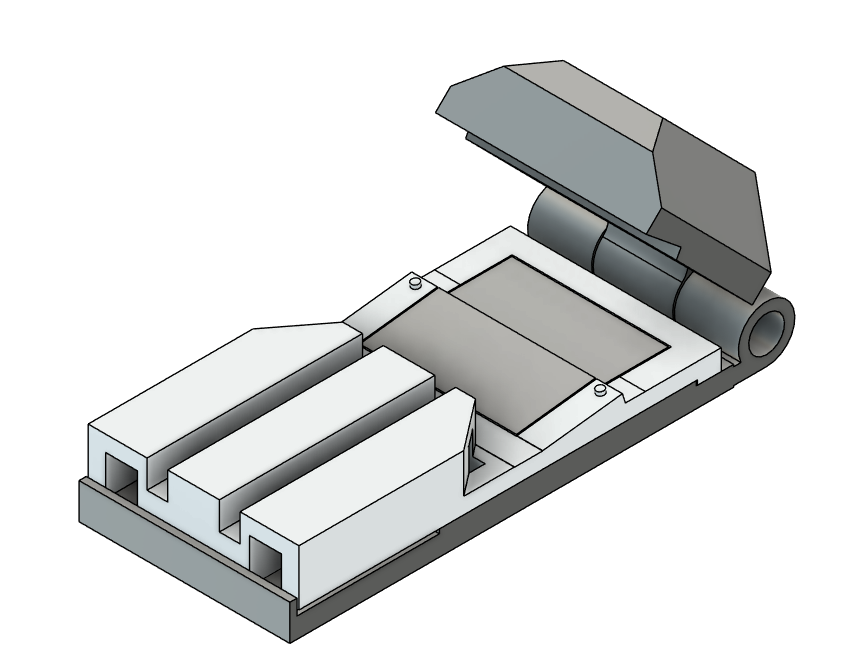
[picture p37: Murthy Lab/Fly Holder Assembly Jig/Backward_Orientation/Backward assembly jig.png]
Backward Assembly Jig


<!-- IMAGE_GALLERY_END -->

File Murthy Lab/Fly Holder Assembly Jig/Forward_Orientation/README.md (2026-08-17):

# Forward_Orientation

<!-- IMAGE_GALLERY_START -->
## Image Gallery

The images below provide a quick visual reference for the files in this folder.

### Forward Assemble Jig

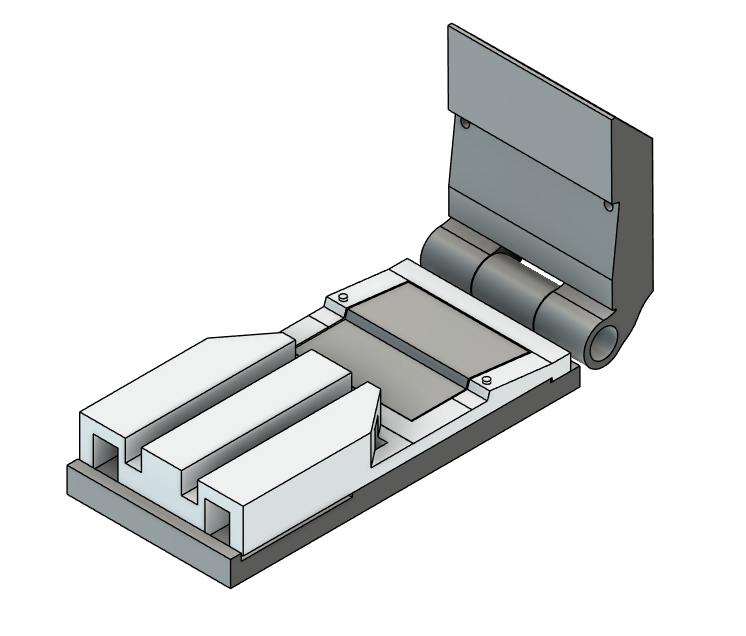
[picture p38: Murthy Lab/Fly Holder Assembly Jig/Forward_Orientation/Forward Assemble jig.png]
Forward Assemble Jig


<!-- IMAGE_GALLERY_END -->

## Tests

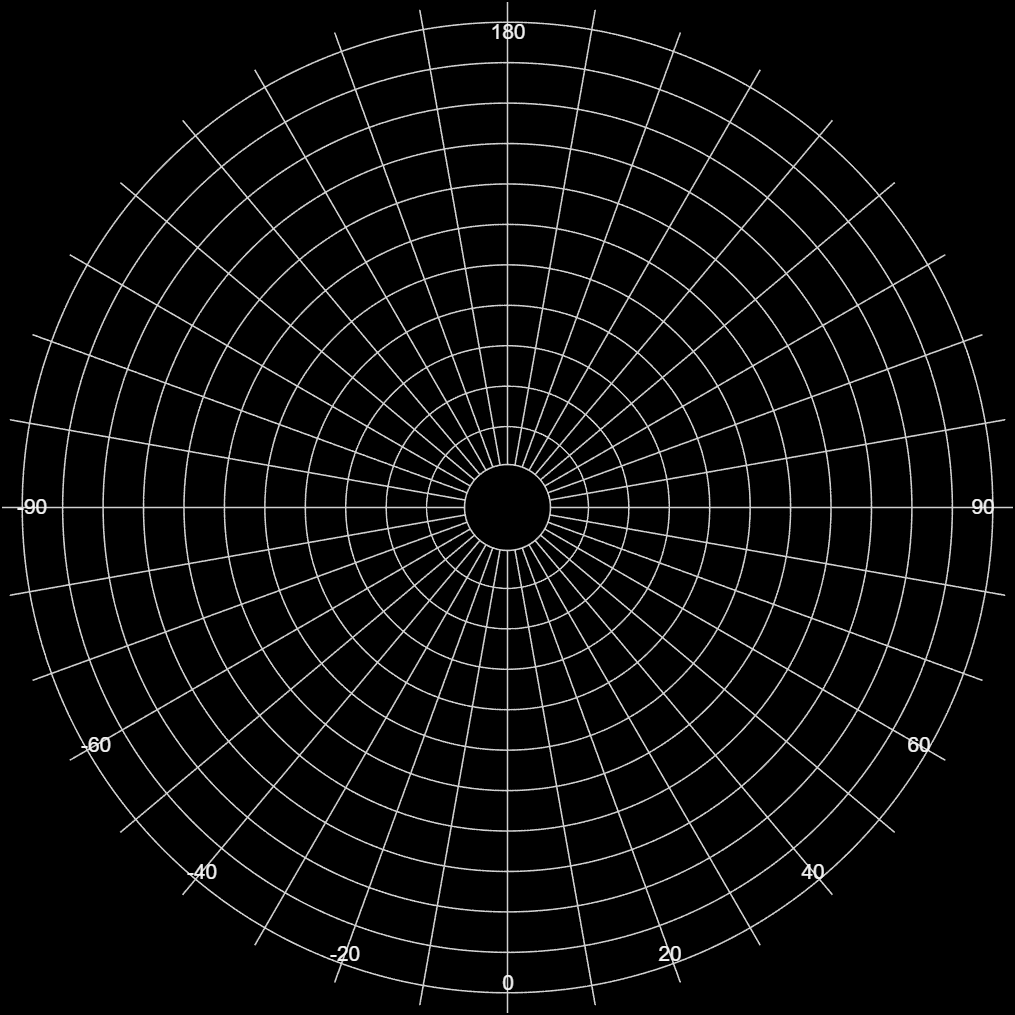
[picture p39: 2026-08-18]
Murthy Lab/Projection/v2/calibration_pattern_v2_preview.png

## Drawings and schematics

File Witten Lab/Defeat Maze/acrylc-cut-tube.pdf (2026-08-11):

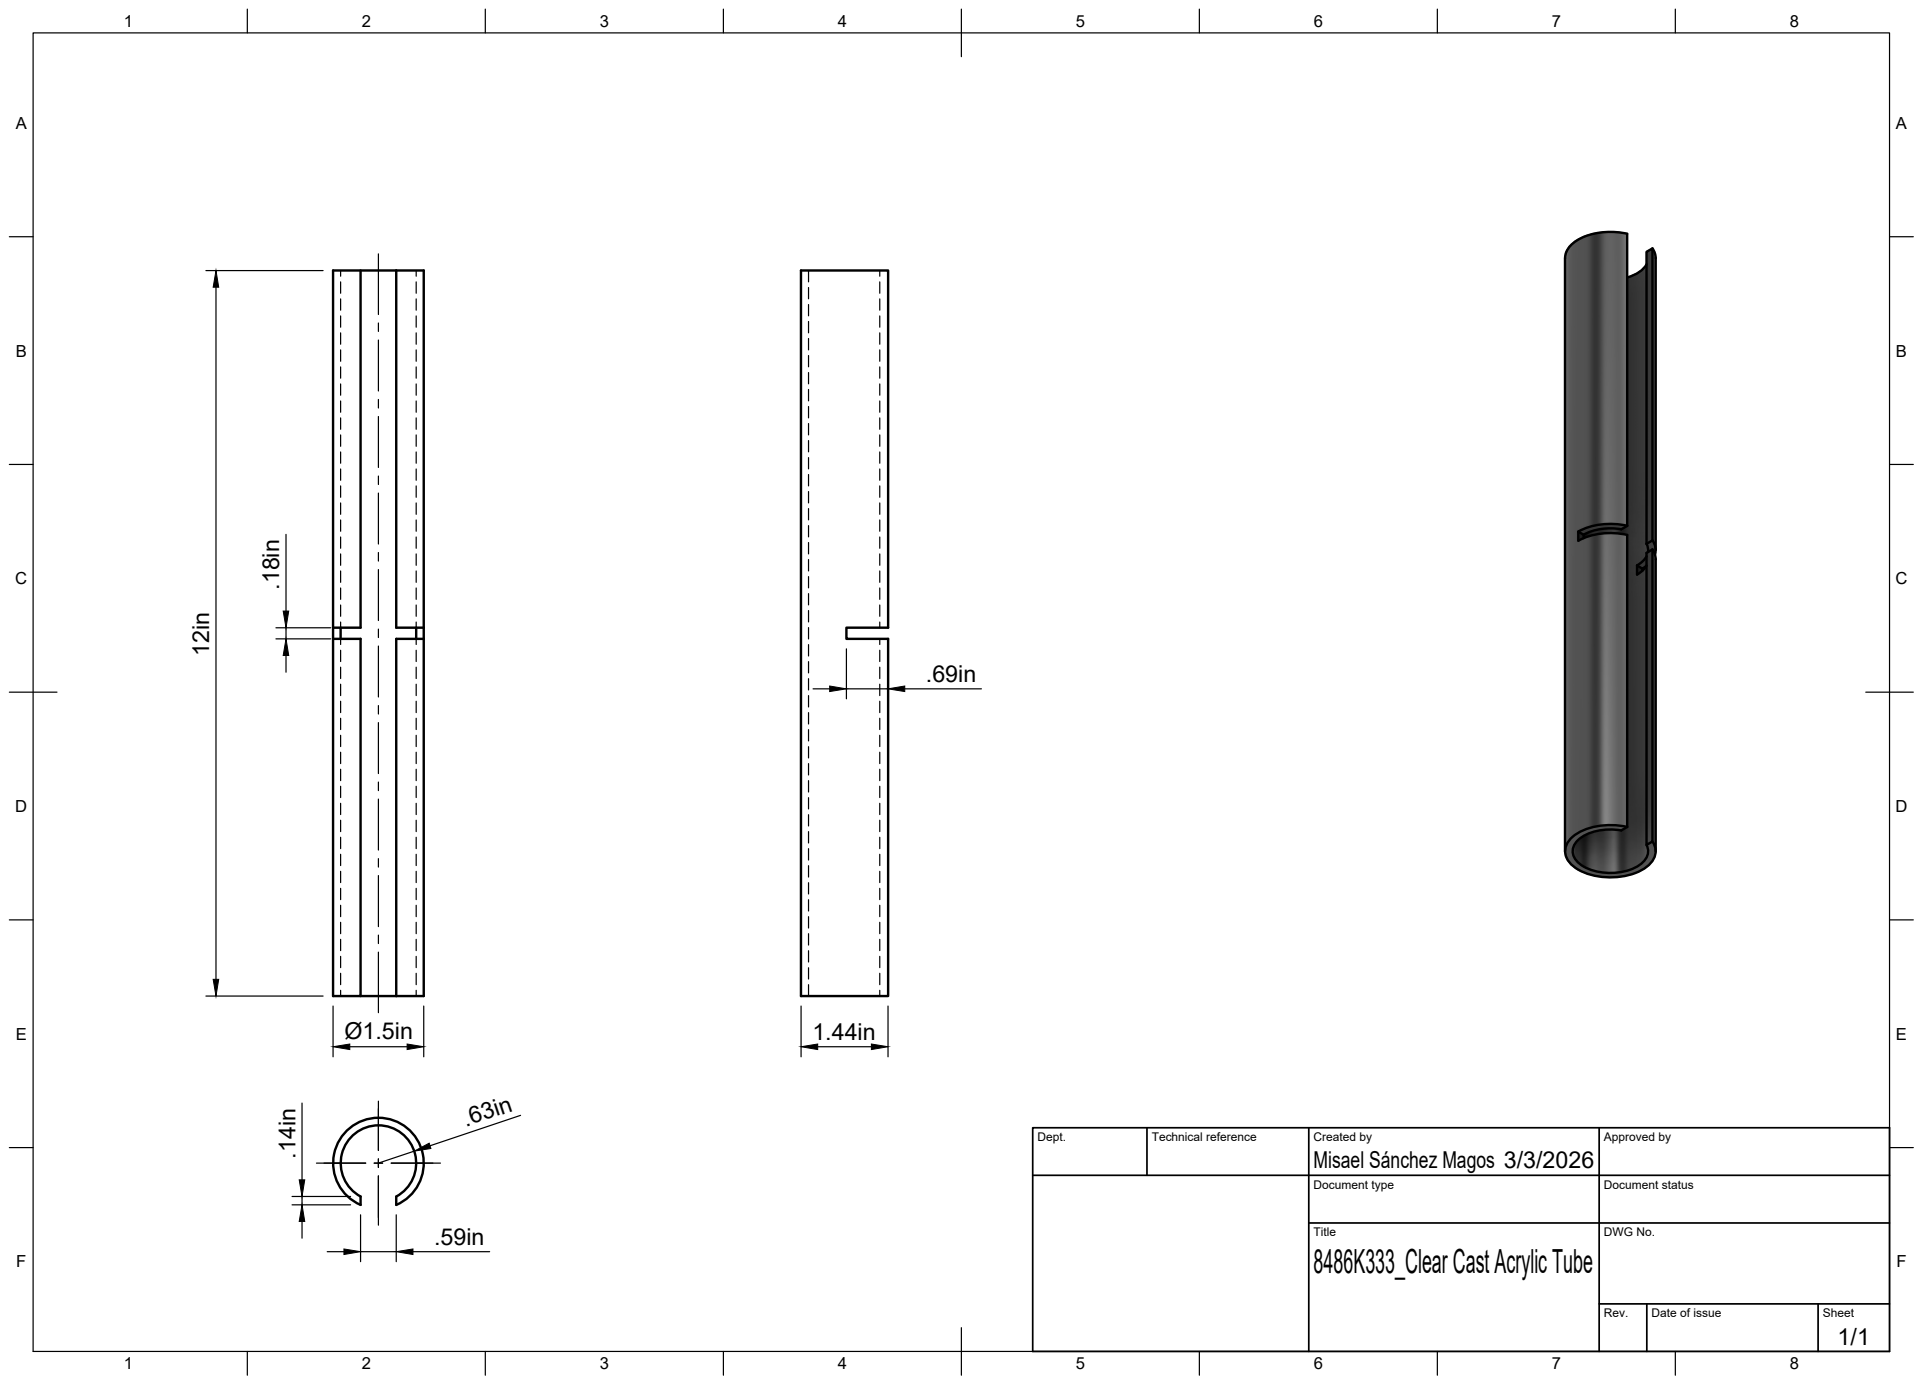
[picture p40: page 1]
Title; DWG No.; Rev.; Date of issue; Sheet

Misael Sánchez Magos 12in

Dept. | Technical reference | Created by 3/3/2026 | Approved by

Document type | Document status

8486K333_Clear Cast Acrylic Tube

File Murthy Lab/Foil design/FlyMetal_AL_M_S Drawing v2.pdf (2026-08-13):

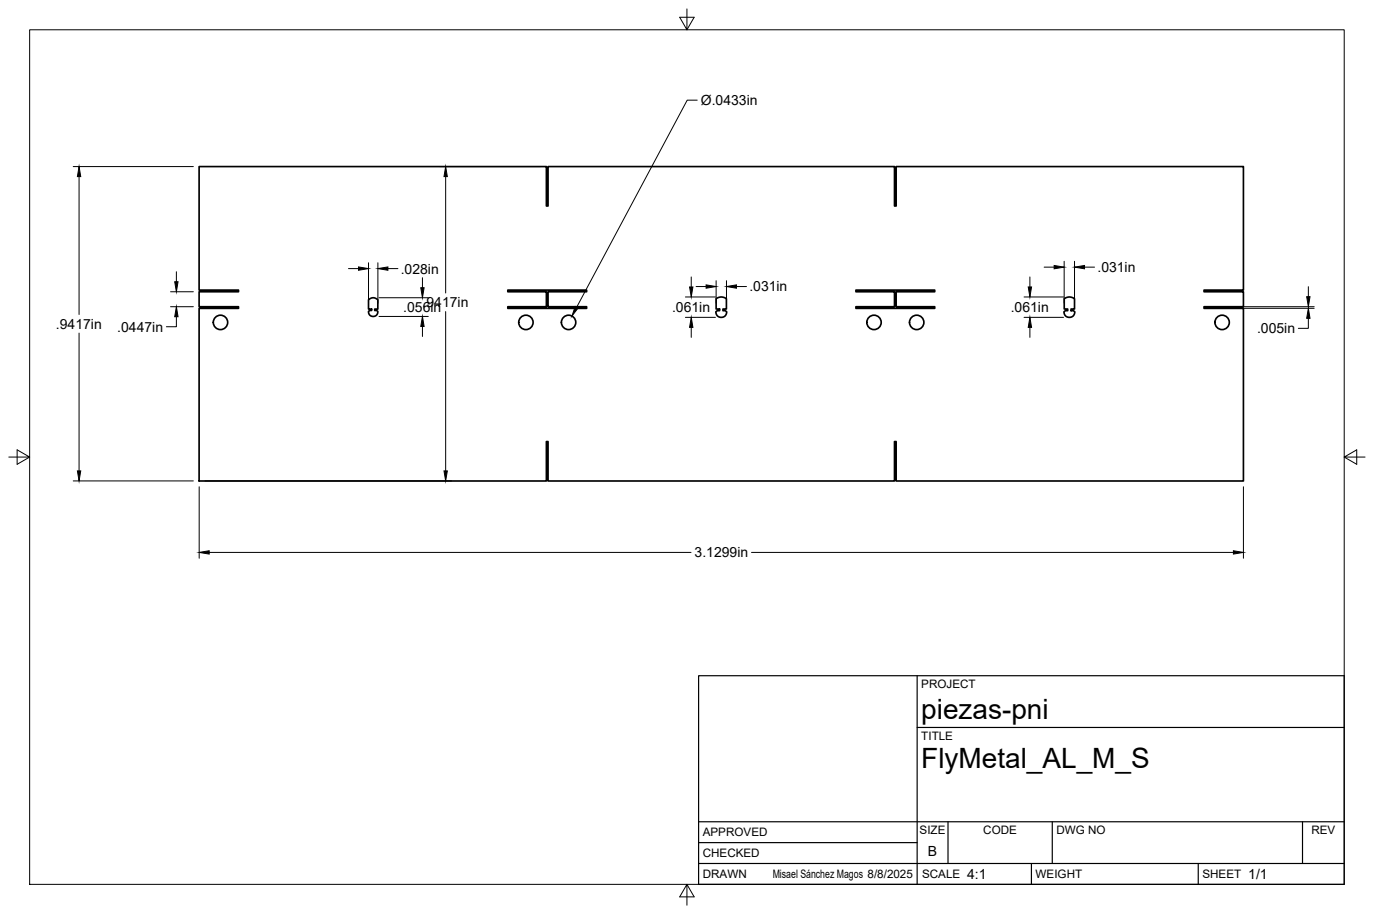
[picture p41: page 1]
SIZE; CODE; DWG NO; REV; Misael Sánchez Magos 8/8/2025

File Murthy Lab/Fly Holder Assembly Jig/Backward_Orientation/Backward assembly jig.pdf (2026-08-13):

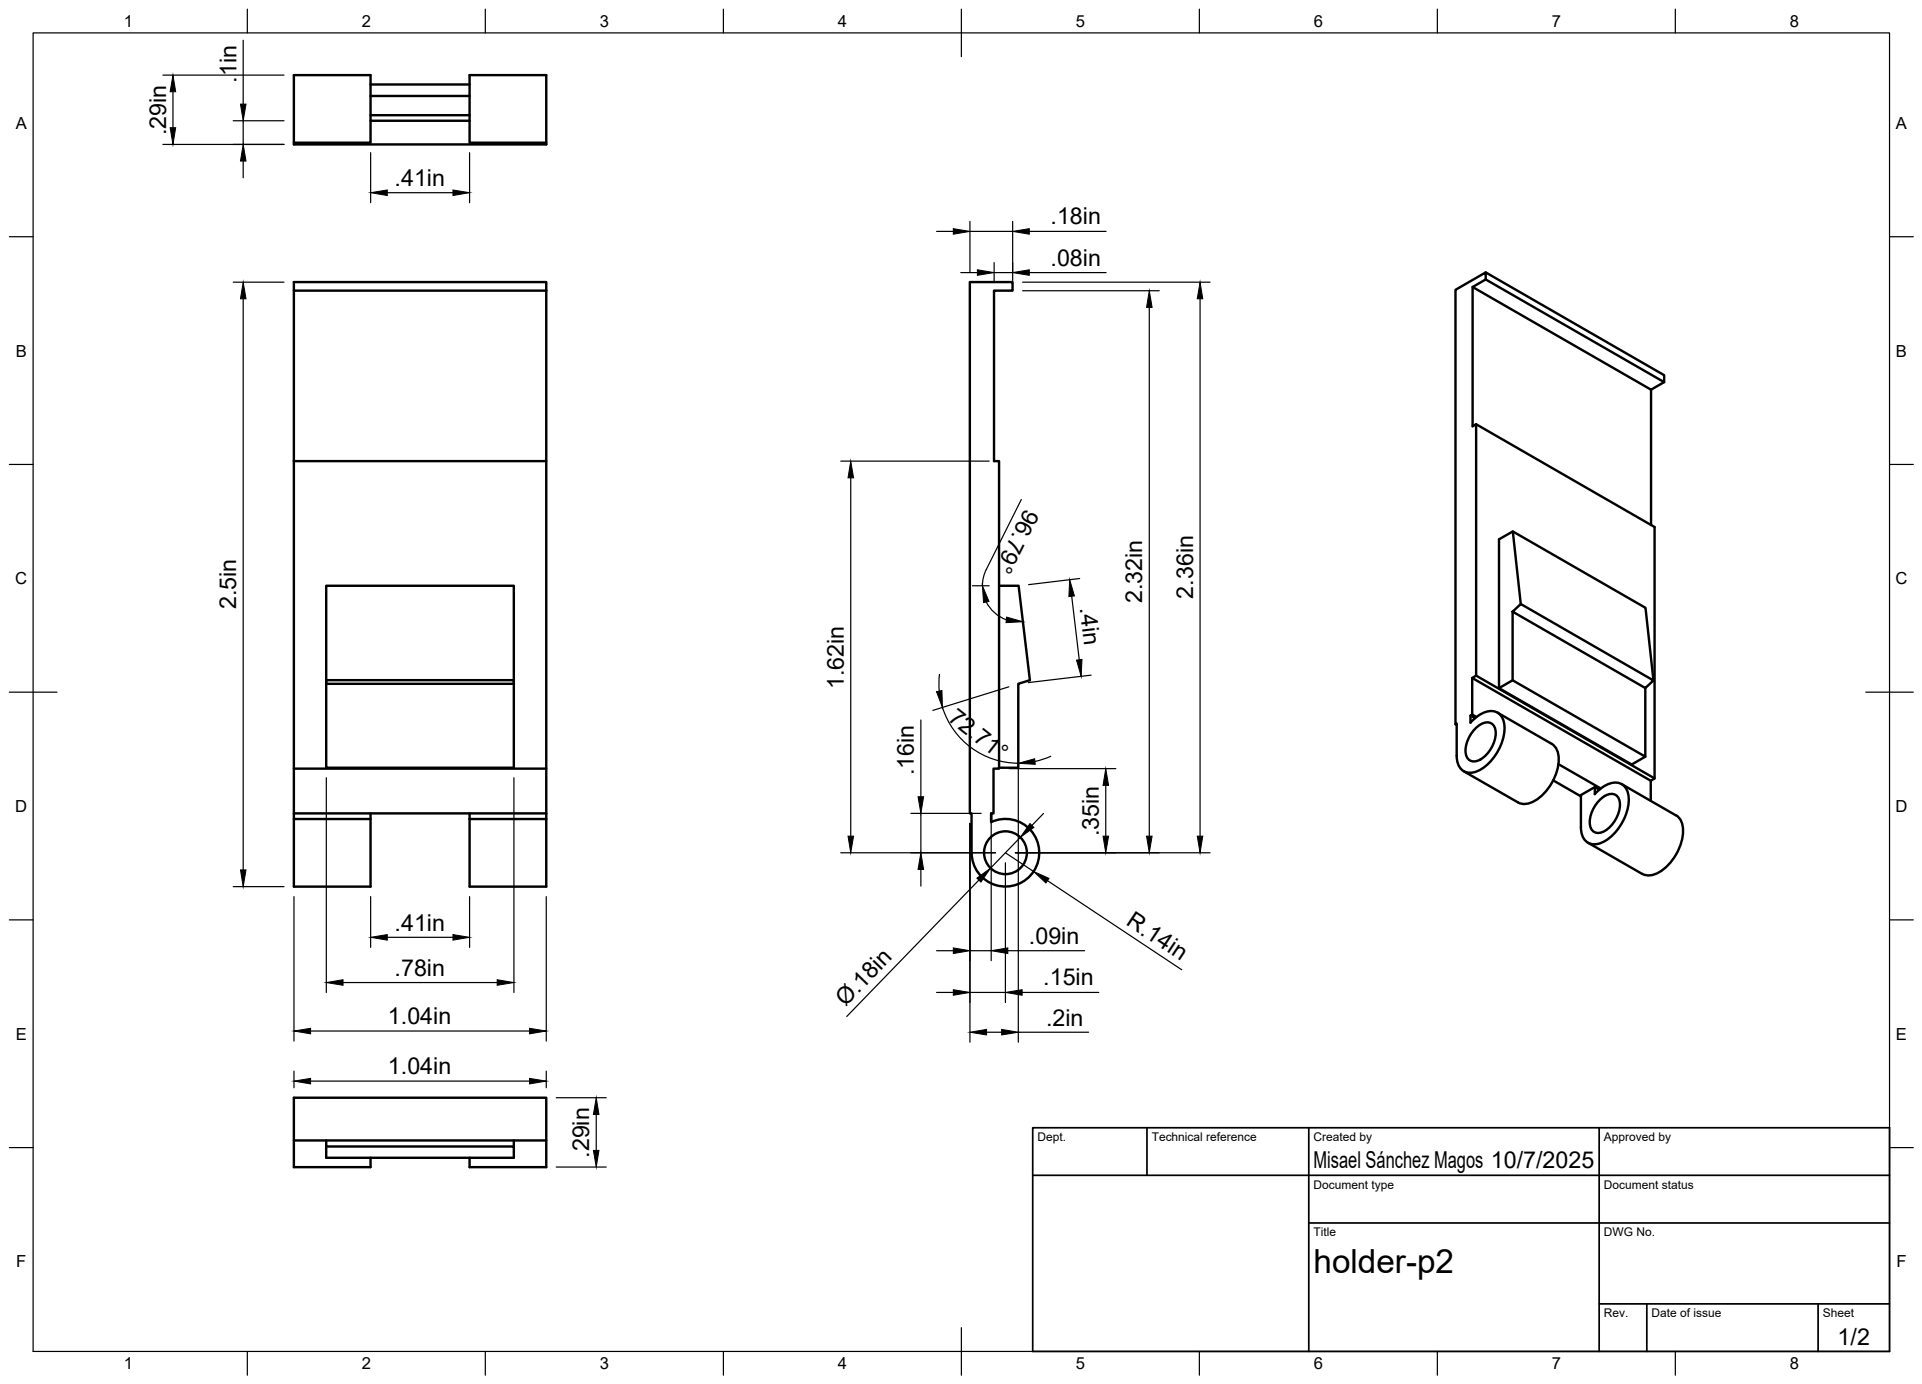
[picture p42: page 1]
8 BCDEF; ABCDEF; Title; DWG No.; Rev.; Date of issue; Sheet

Misael Sánchez Magos 2.5in

Dept. | Technical reference | Created by 10/7/2025 | Approved by

Document type | Document status

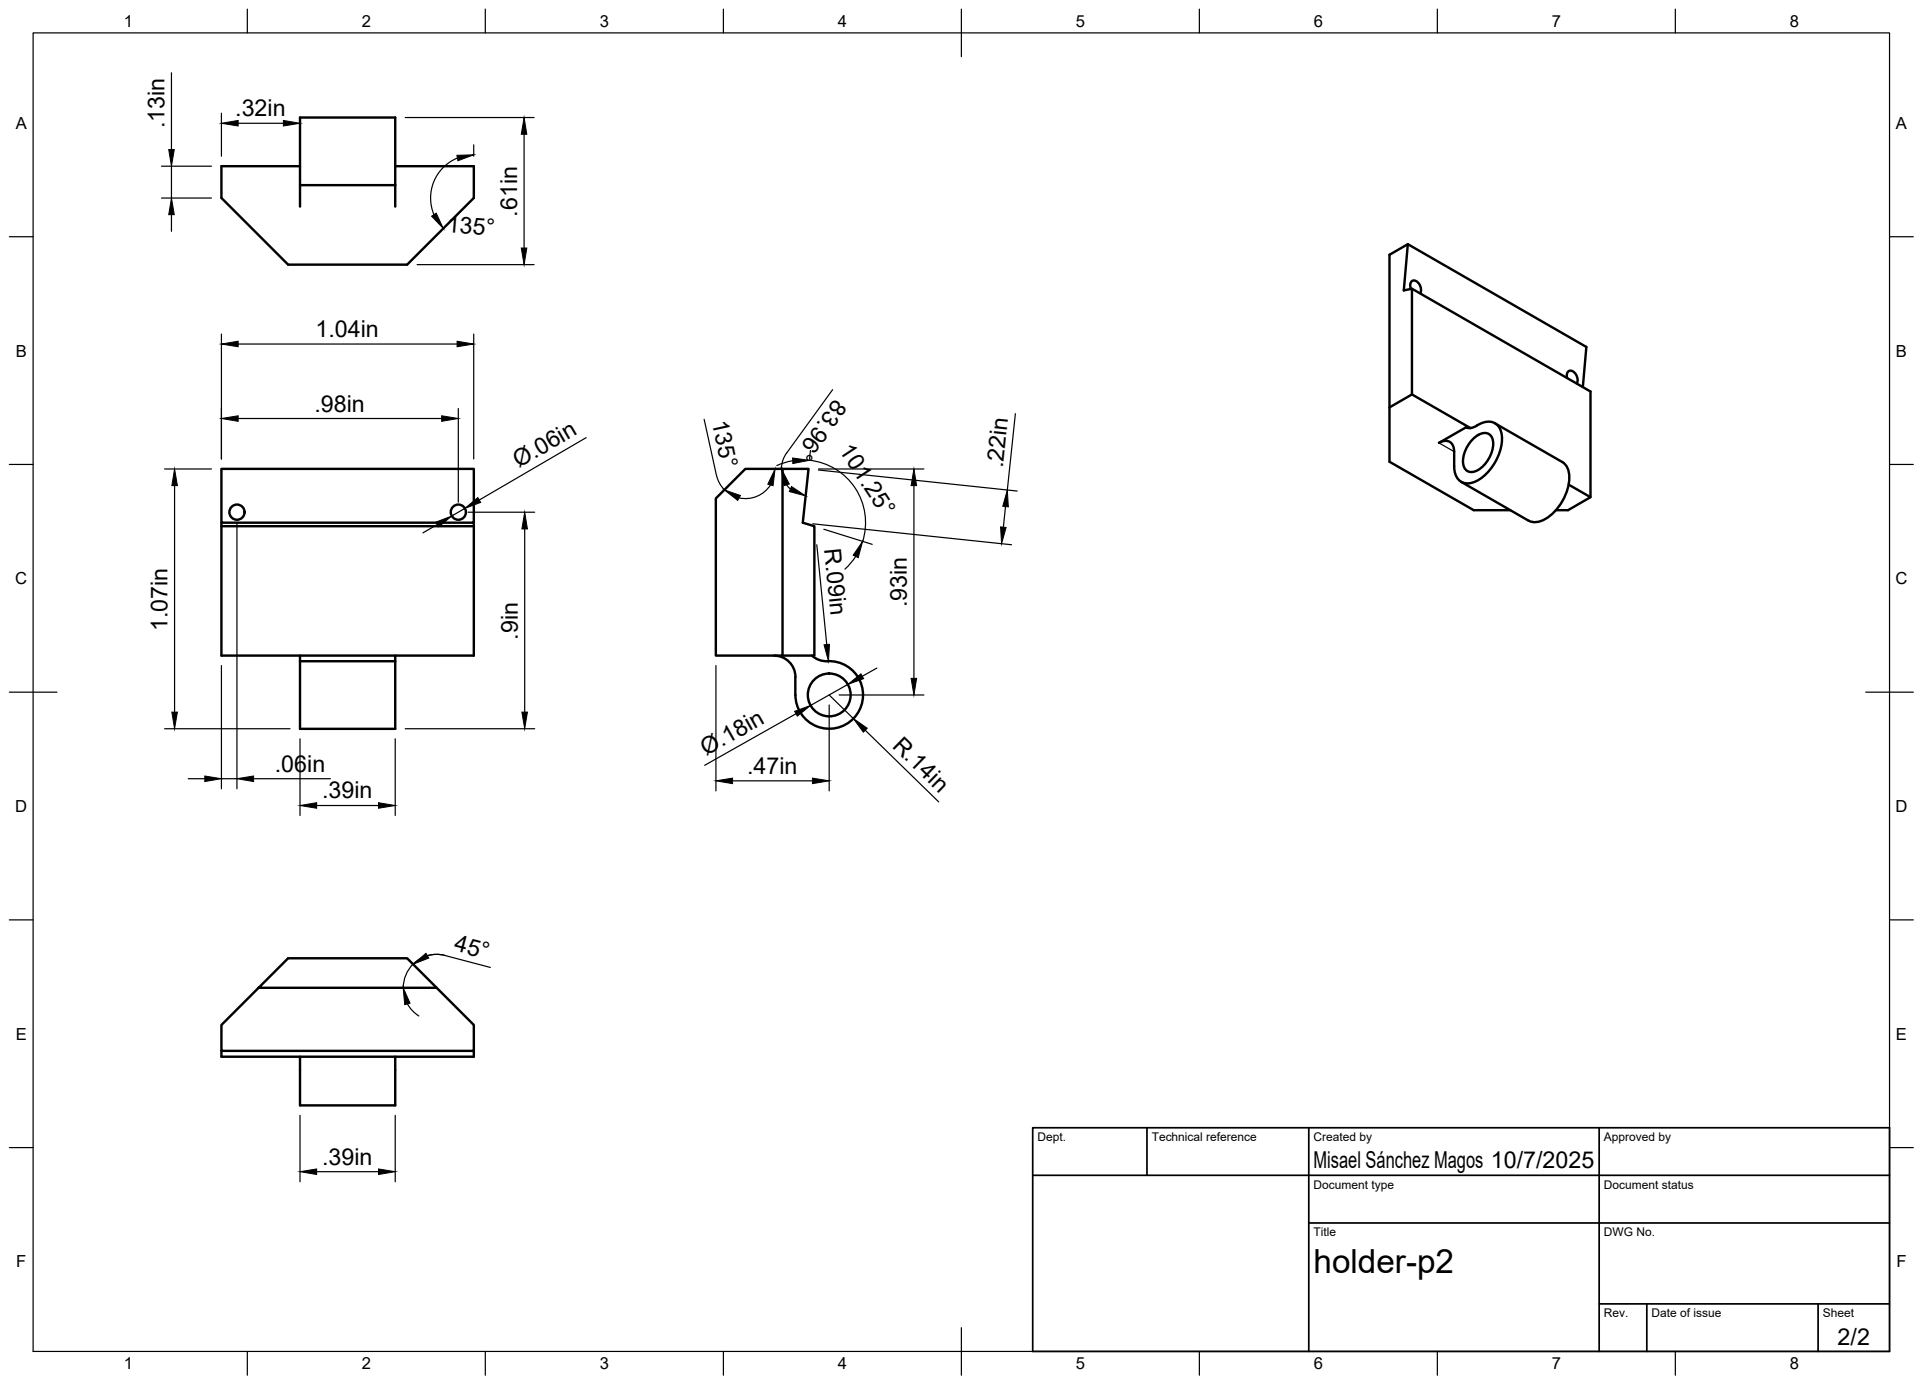
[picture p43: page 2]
Title; DWG No.; Rev.; Date of issue; Sheet

Dept. | Technical reference | Created by Misael Sánchez Magos 10/7/2025 | Approved by

Document type | Document status

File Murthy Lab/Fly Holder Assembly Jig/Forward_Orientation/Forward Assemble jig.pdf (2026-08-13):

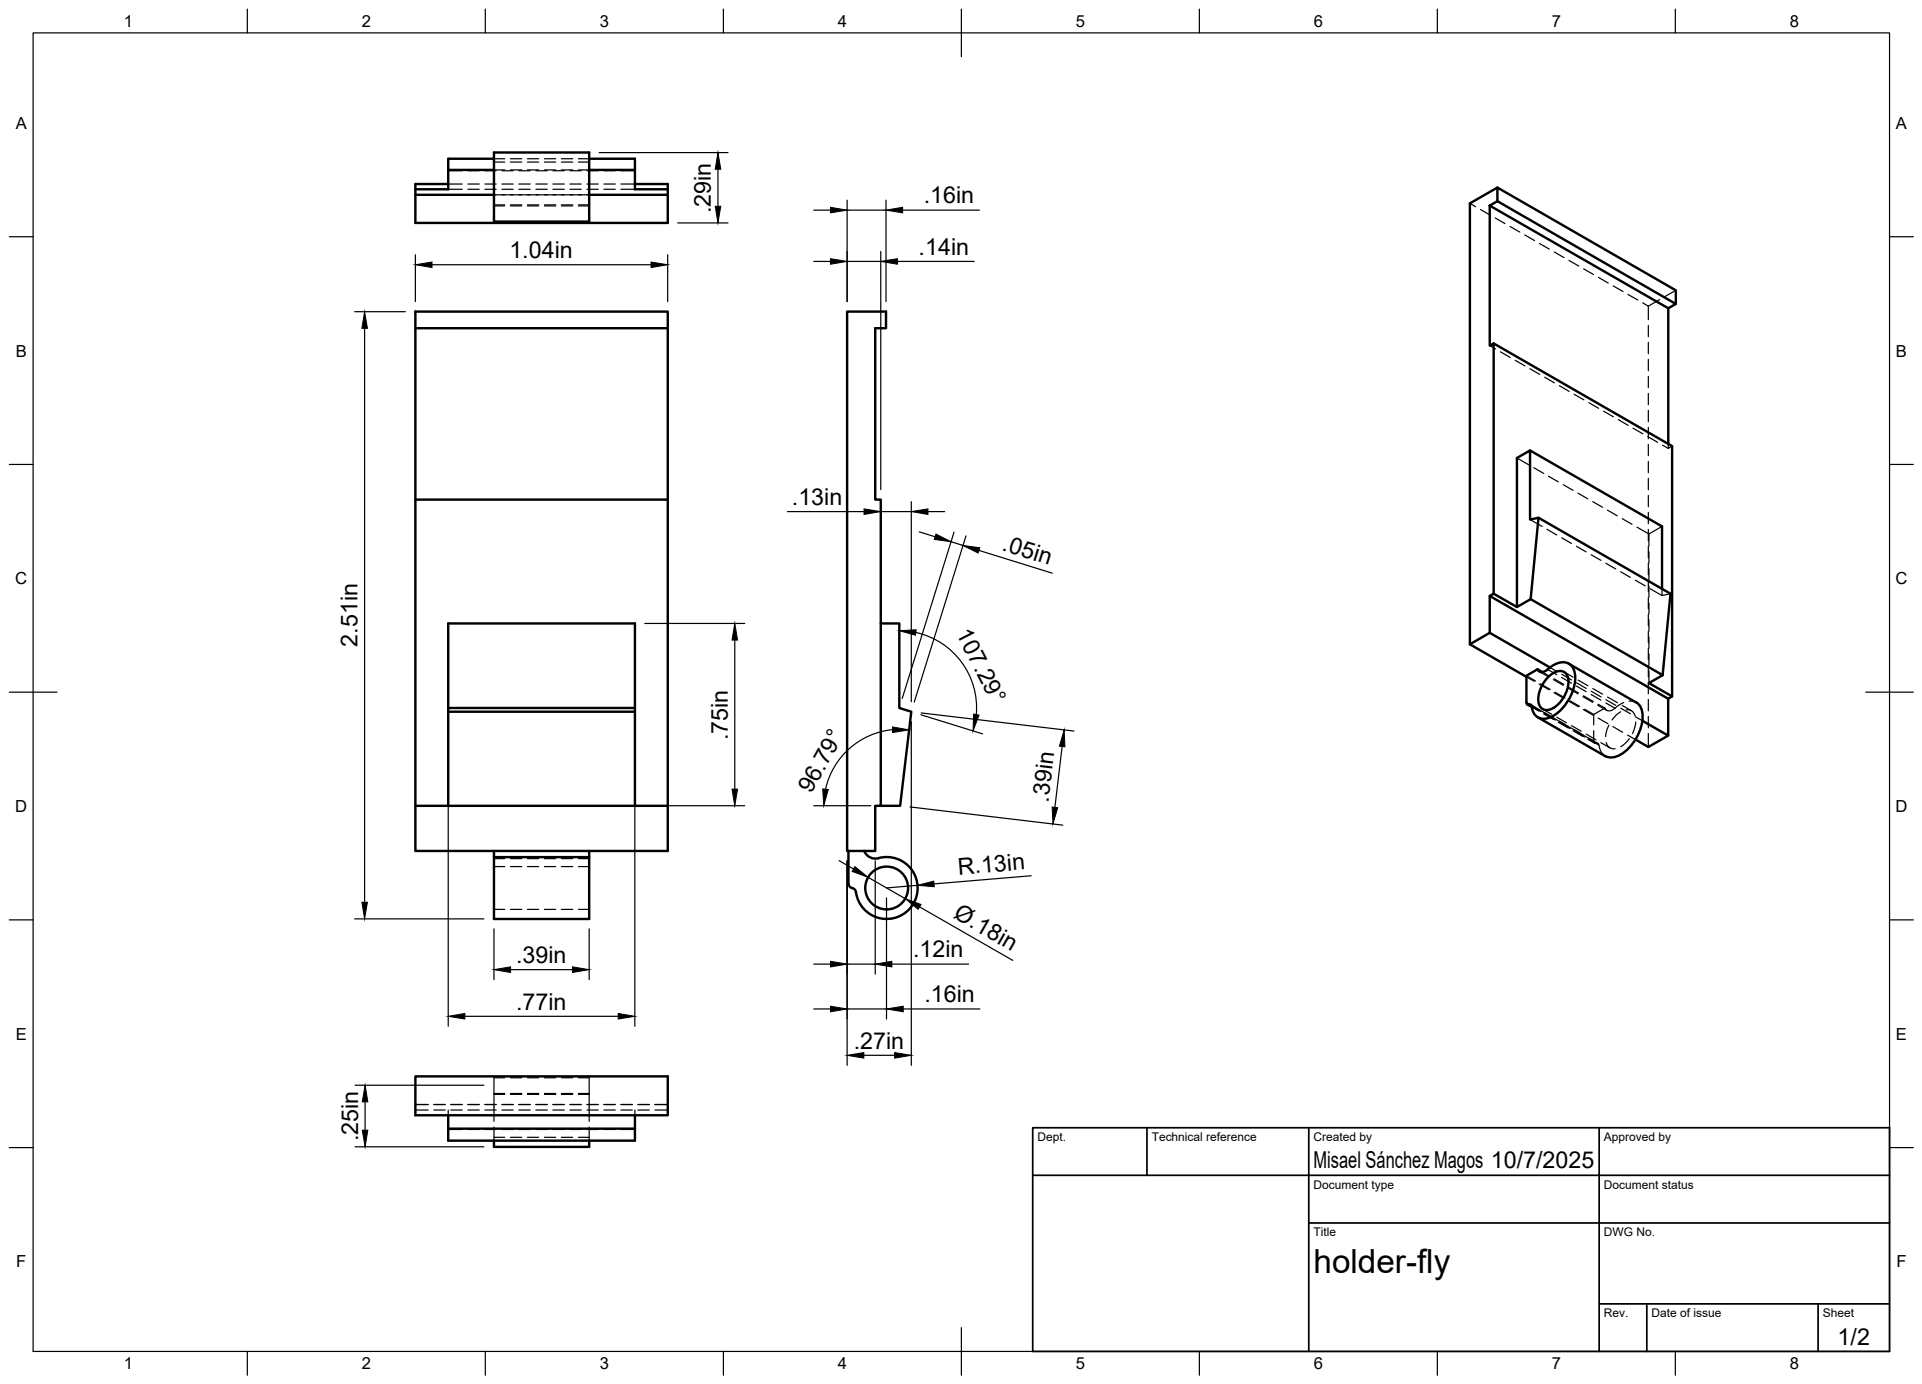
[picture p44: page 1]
Title; DWG No.; Rev.; Date of issue; Sheet

Dept. | Technical reference | Created by Misael Sánchez Magos 10/7/2025 | Approved by

Document type | Document status

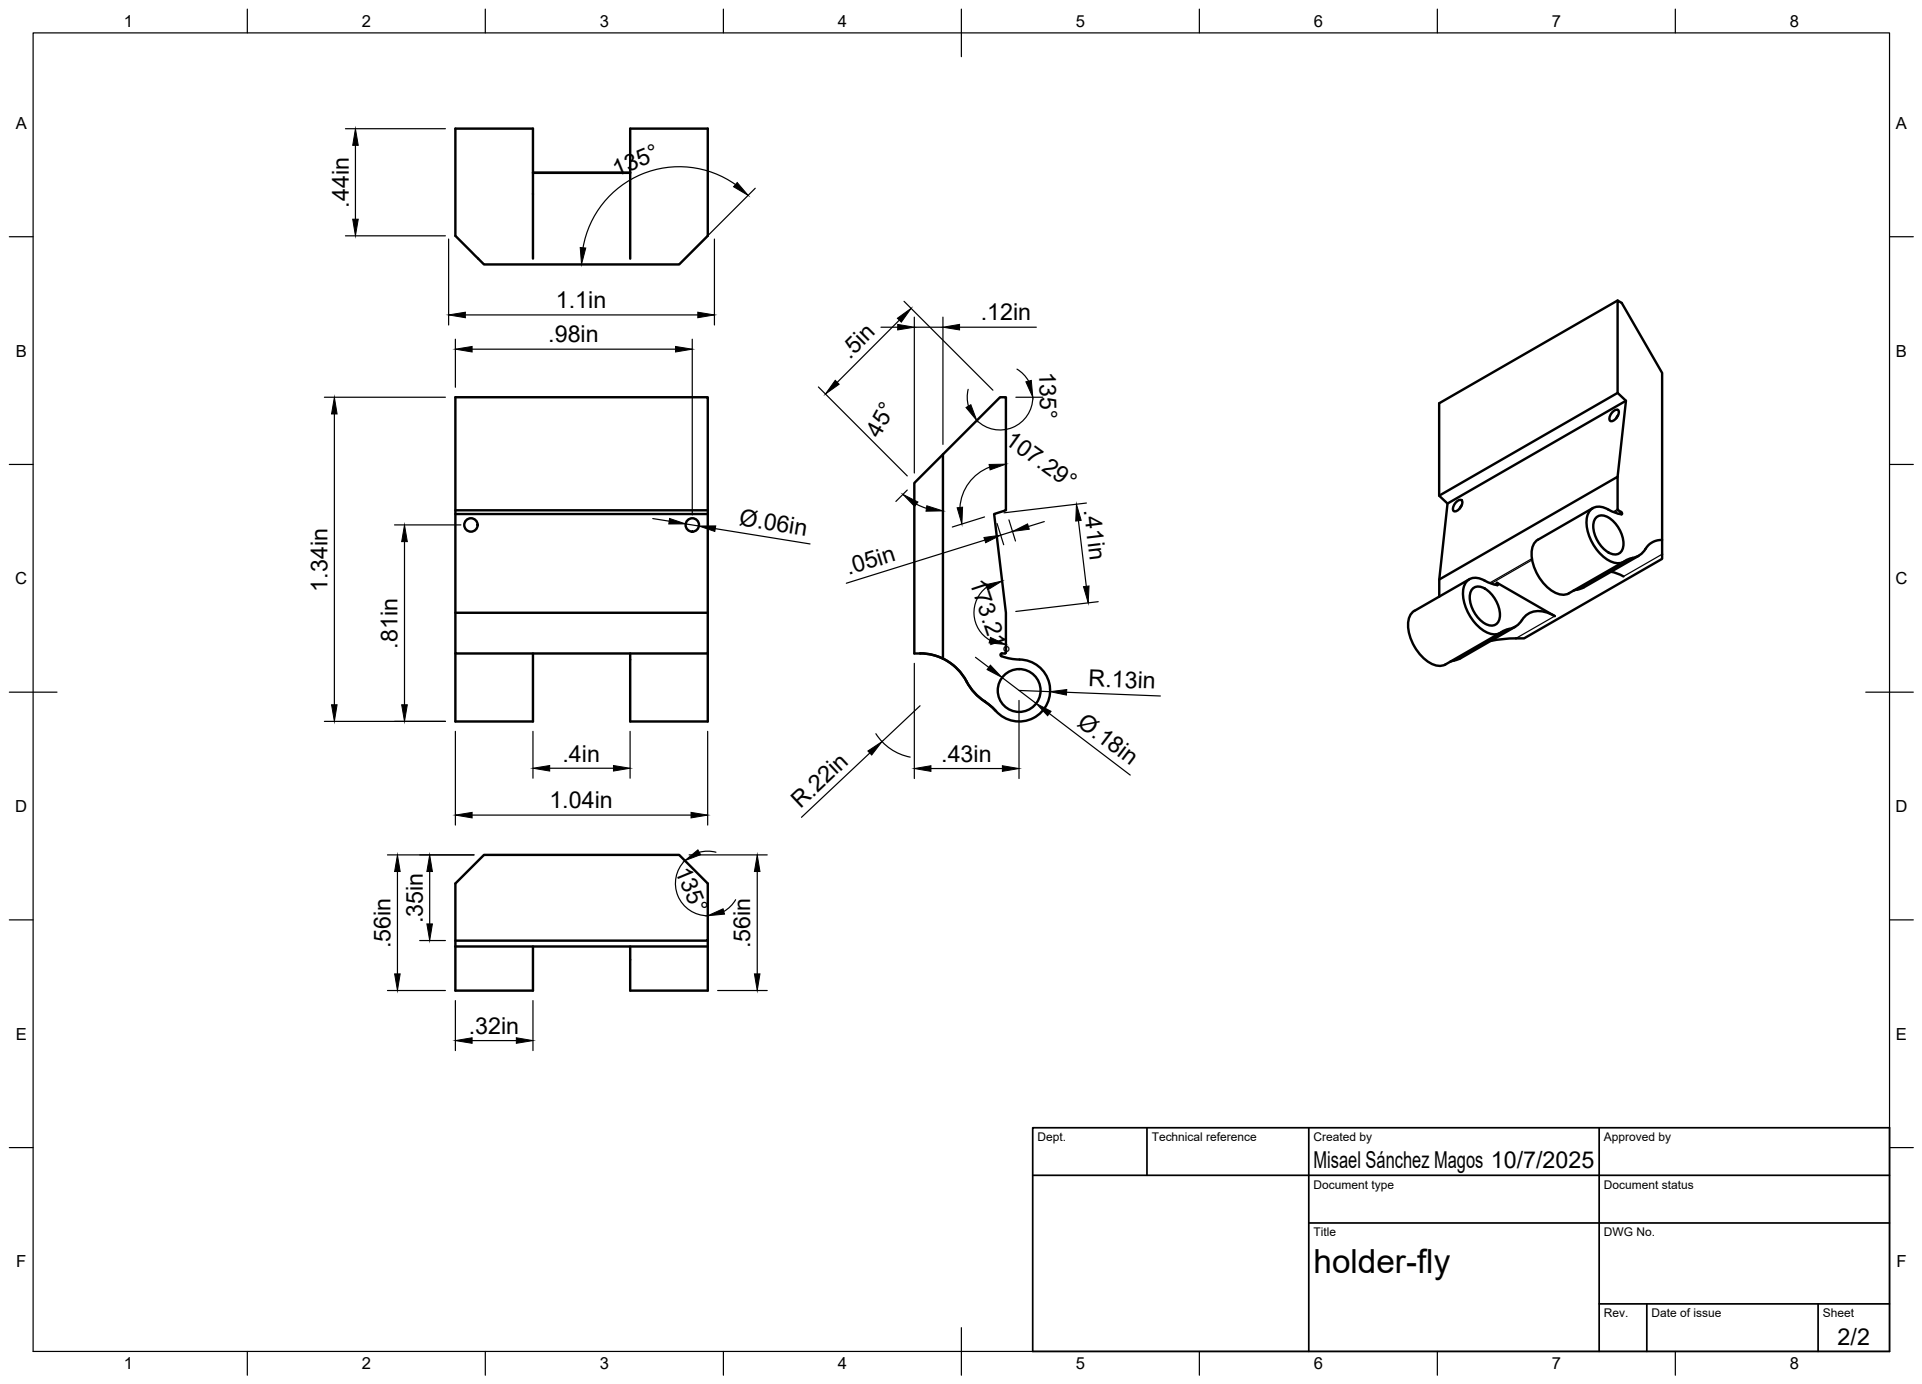
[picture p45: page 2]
Title; DWG No.; Rev.; Date of issue; Sheet

Misael Sánchez Magos 1.34in

Dept. | Technical reference | Created by 10/7/2025 | Approved by

Document type | Document status

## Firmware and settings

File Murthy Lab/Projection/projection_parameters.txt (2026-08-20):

%% Mini VR projection parameters
% Spherical screen radius
proj_param_Rs           =   8;

% Screen's center location relative to the animal eyes
proj_param_xsm          =   1.814;
proj_param_ysm          =   0;
proj_param_zsm          =   0.47;

% Mirror position relative to the animal eyes
% Mirror position measurement is facilitated knowing that the center of 
% spherical mirror is (43.8-24.2=)19.6mm (0.77in) behind the back surface.
proj_param_xOm          =   5.582;
proj_param_yOm          =   0;
proj_param_zOm          =   -6.62;

% Radius of the spherical mirror (Silver coated lens LA1740-Thorlabs)
proj_param_r            =   1.724;

% Projector position relative to the mirror center
proj_param_xP1o         =   11.1;
proj_param_yP1o         =   0;
proj_param_zP1o         =   -0.6;

% Horizontal coordinate shift and rescaling
proj_param_hrescaling   =   5.5;
proj_param_hshift       =   0;

% Vertical coordinate shift and rescaling
proj_param_vrescaling   =   5.5;
proj_param_vshift       =   -1.017;

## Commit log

2026-08-11 1st update
    [8486K333_Clear Cast Acrylic Tube.step, Body1.stl, Component1.stl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]
2026-08-20 new calibration
    [projection_parameters.txt]
